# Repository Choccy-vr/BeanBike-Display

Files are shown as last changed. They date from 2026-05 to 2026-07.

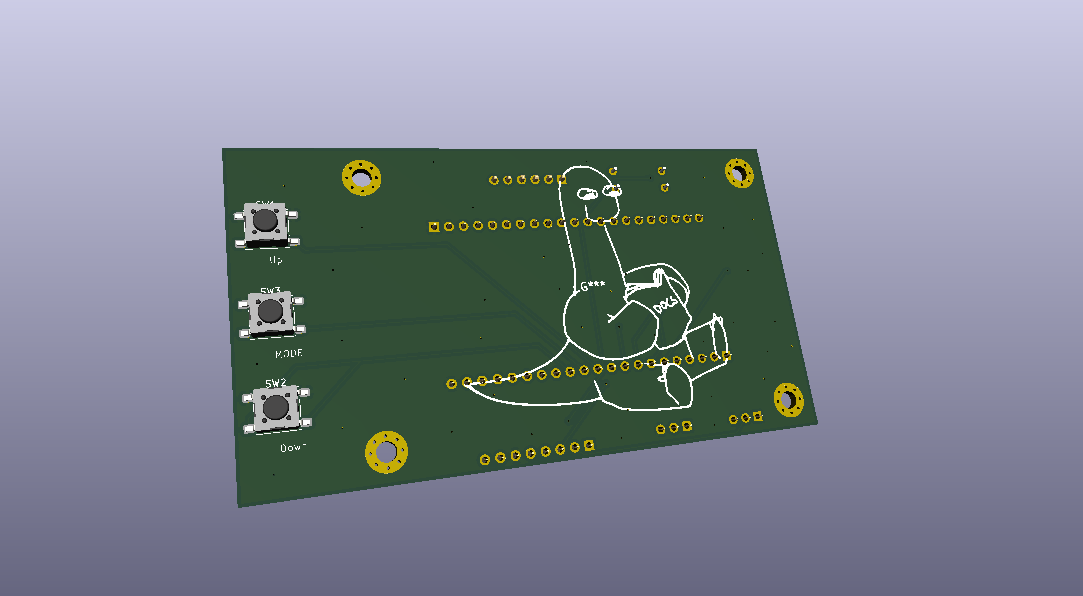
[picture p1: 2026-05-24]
Images/PCB-Bottom.png

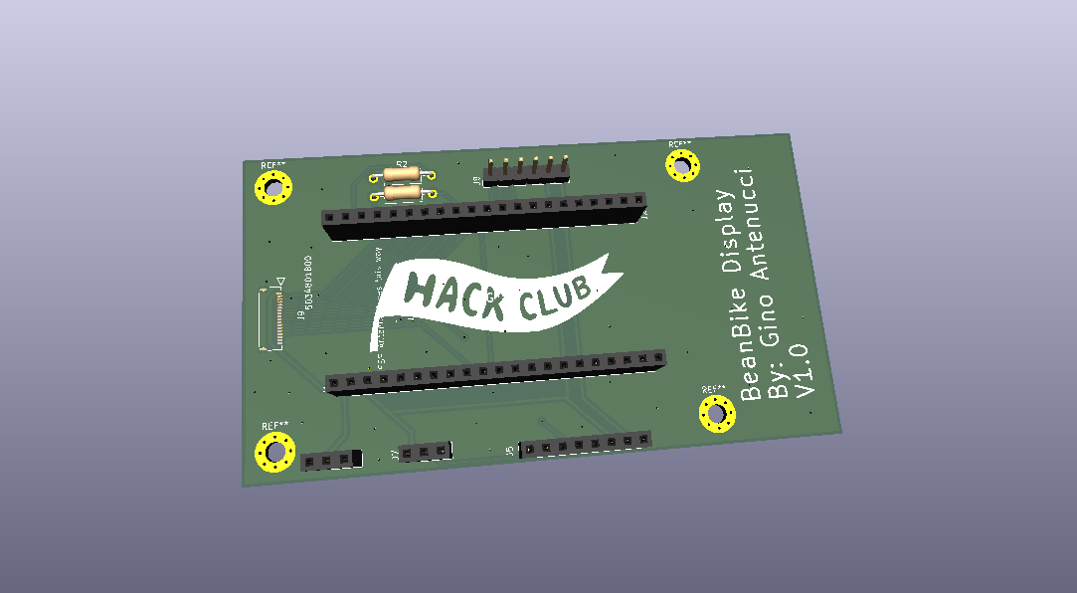
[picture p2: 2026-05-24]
Images/PCB-Top.png

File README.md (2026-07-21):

# BeanBike-Display
### Description
A smart display to use with VESC controllers for Hack Club's Goated YSWS Macondo!!
### Demo
Here is a demo video on YouTube. https://youtu.be/hzEWeqmnlWU
### Specs
- ESP32 S3 N16R8
- Waveshare 480x320 capasitive display
- Custom PCB
### Detailed Description
A smart display using an ESP32 S3 and custom-developed firmware to communicate with VESC devices. Built for eBikes, BeanBike-Display can connect to virtually any VESC controller. With a beautiful 480x320 display from Waveshare to pair with UI designed in Squareline Vision and built with LVGL for fast, beautiful UIs. 
### Why I made this
I made this because I love mobility projects (like e-bikes or anything that moves you around); they are just so fun. This is a successor in a way to a previous project where I tried to create my own BLDC controller (it didn't go well), so this time I am making the display with all the smart functionality and VESC)
### BOM
Note that these are the things that I need funded. Everything else I already have. (The build cost on Macondo is outdated, but I couldn't change it. The cart pics are mostly the same, just with some stuff removed)
|Product Name |Product Description  |Product Link |Product unit price|Product amount|Product Cost|Total (Before Tax + Shipping)|Total (Without Shipping)|Total |
|---|---|---|---|---|---|---|---|---|
|FPC Connector|Connecting to dosplay|https://www.digikey.com/en/products/detail/molex/5034801800/2819155?s=N4IgTCBcDaIKwAYDMAWAHAgjBhIC6AvkA |$1.50 |1 |$1.50 |$8.70 |$9.31 |$19.36|
|PCB |uhh PCB |https://cart.jlcpcb.com/shopcart/cart |$2 |1 |$2 | | | |
|Headers |connecting to ESP |https://www.aliexpress.us/item/3256810564318830.html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|$2.60 |2 |$5.20 | | | |
### Firmware
Open up the firmware folder in PlatformIO and press upload!
## Images

### UI

#### Mockup


#### Built UI


### PCB

#### Schematic


#### Layout


#### 3D PCB
Beanbike-Display
Beanbike-Display-Back

### Built Images





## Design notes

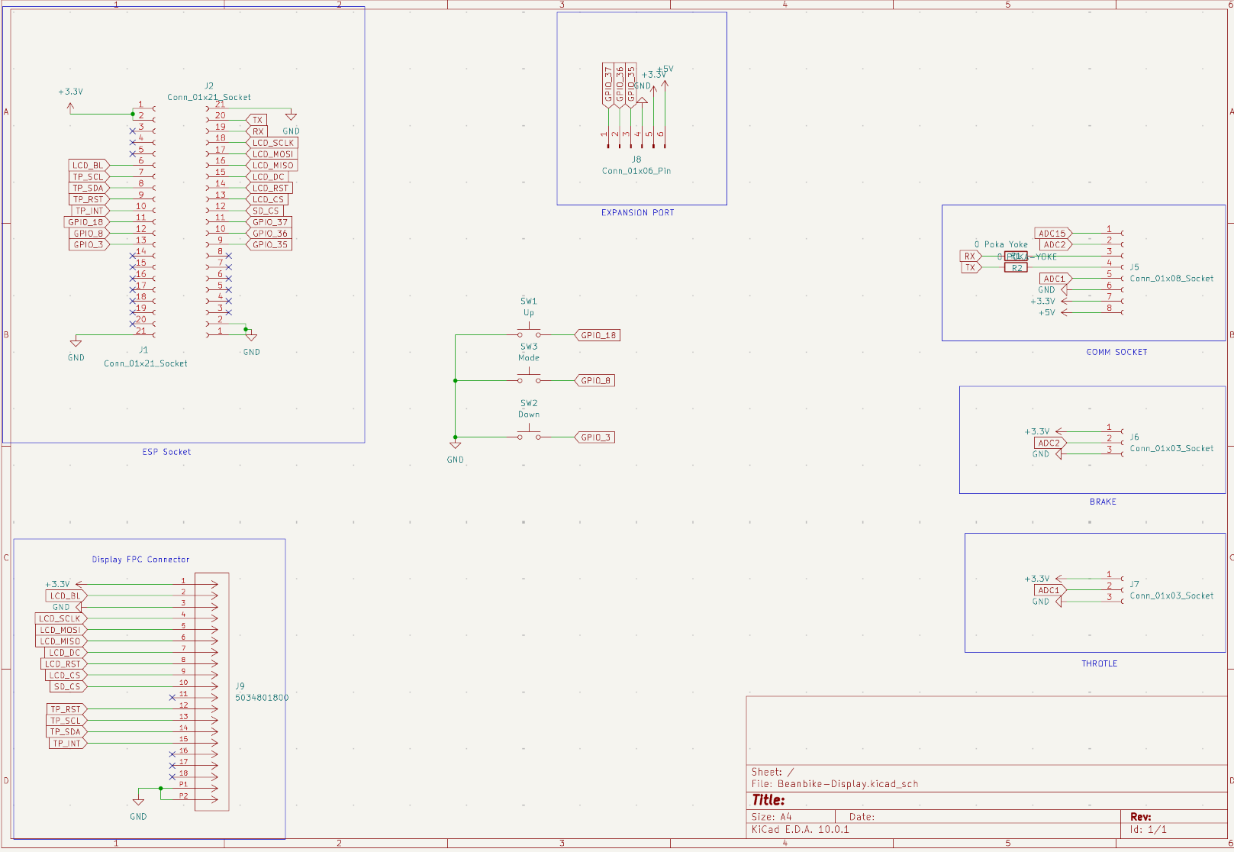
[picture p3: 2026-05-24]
Images/Schematic.png

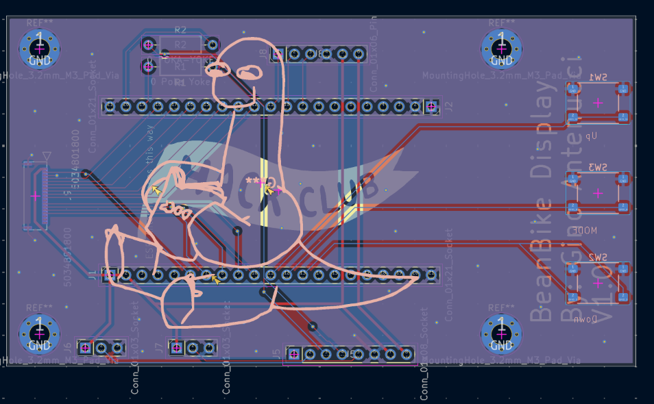
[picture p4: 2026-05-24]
Images/PCB.png

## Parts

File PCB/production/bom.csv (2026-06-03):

Designator | Footprint | Quantity | Value | LCSC Part #
J1, J2 | PinSocket_1x21_P2.54mm_Vertical | 2 | Conn_01x21_Socket
J5 | PinSocket_1x08_P2.54mm_Vertical | 1 | Conn_01x08_Socket
J6, J7 | PinSocket_1x03_P2.54mm_Vertical | 2 | Conn_01x03_Socket
J8 | PinHeader_1x06_P2.54mm_Vertical | 1 | Conn_01x06_Pin
J9 | CON_5034801800_MOL | 1 | 5034801800

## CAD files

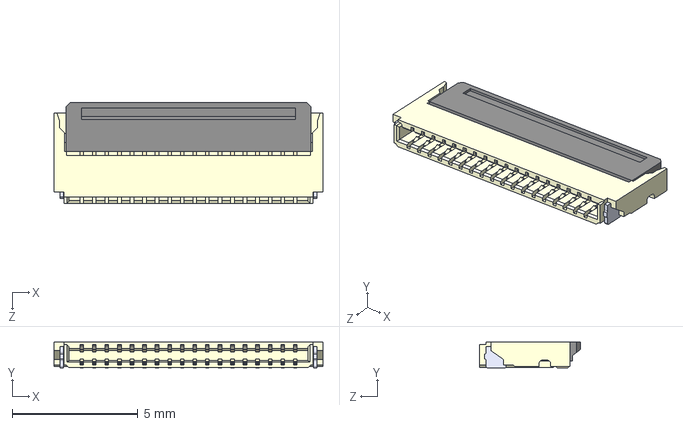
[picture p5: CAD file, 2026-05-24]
PCB/Resources/5034801800 (1)/5034801800.step
10.7 x 1.02 x 4.00 mm

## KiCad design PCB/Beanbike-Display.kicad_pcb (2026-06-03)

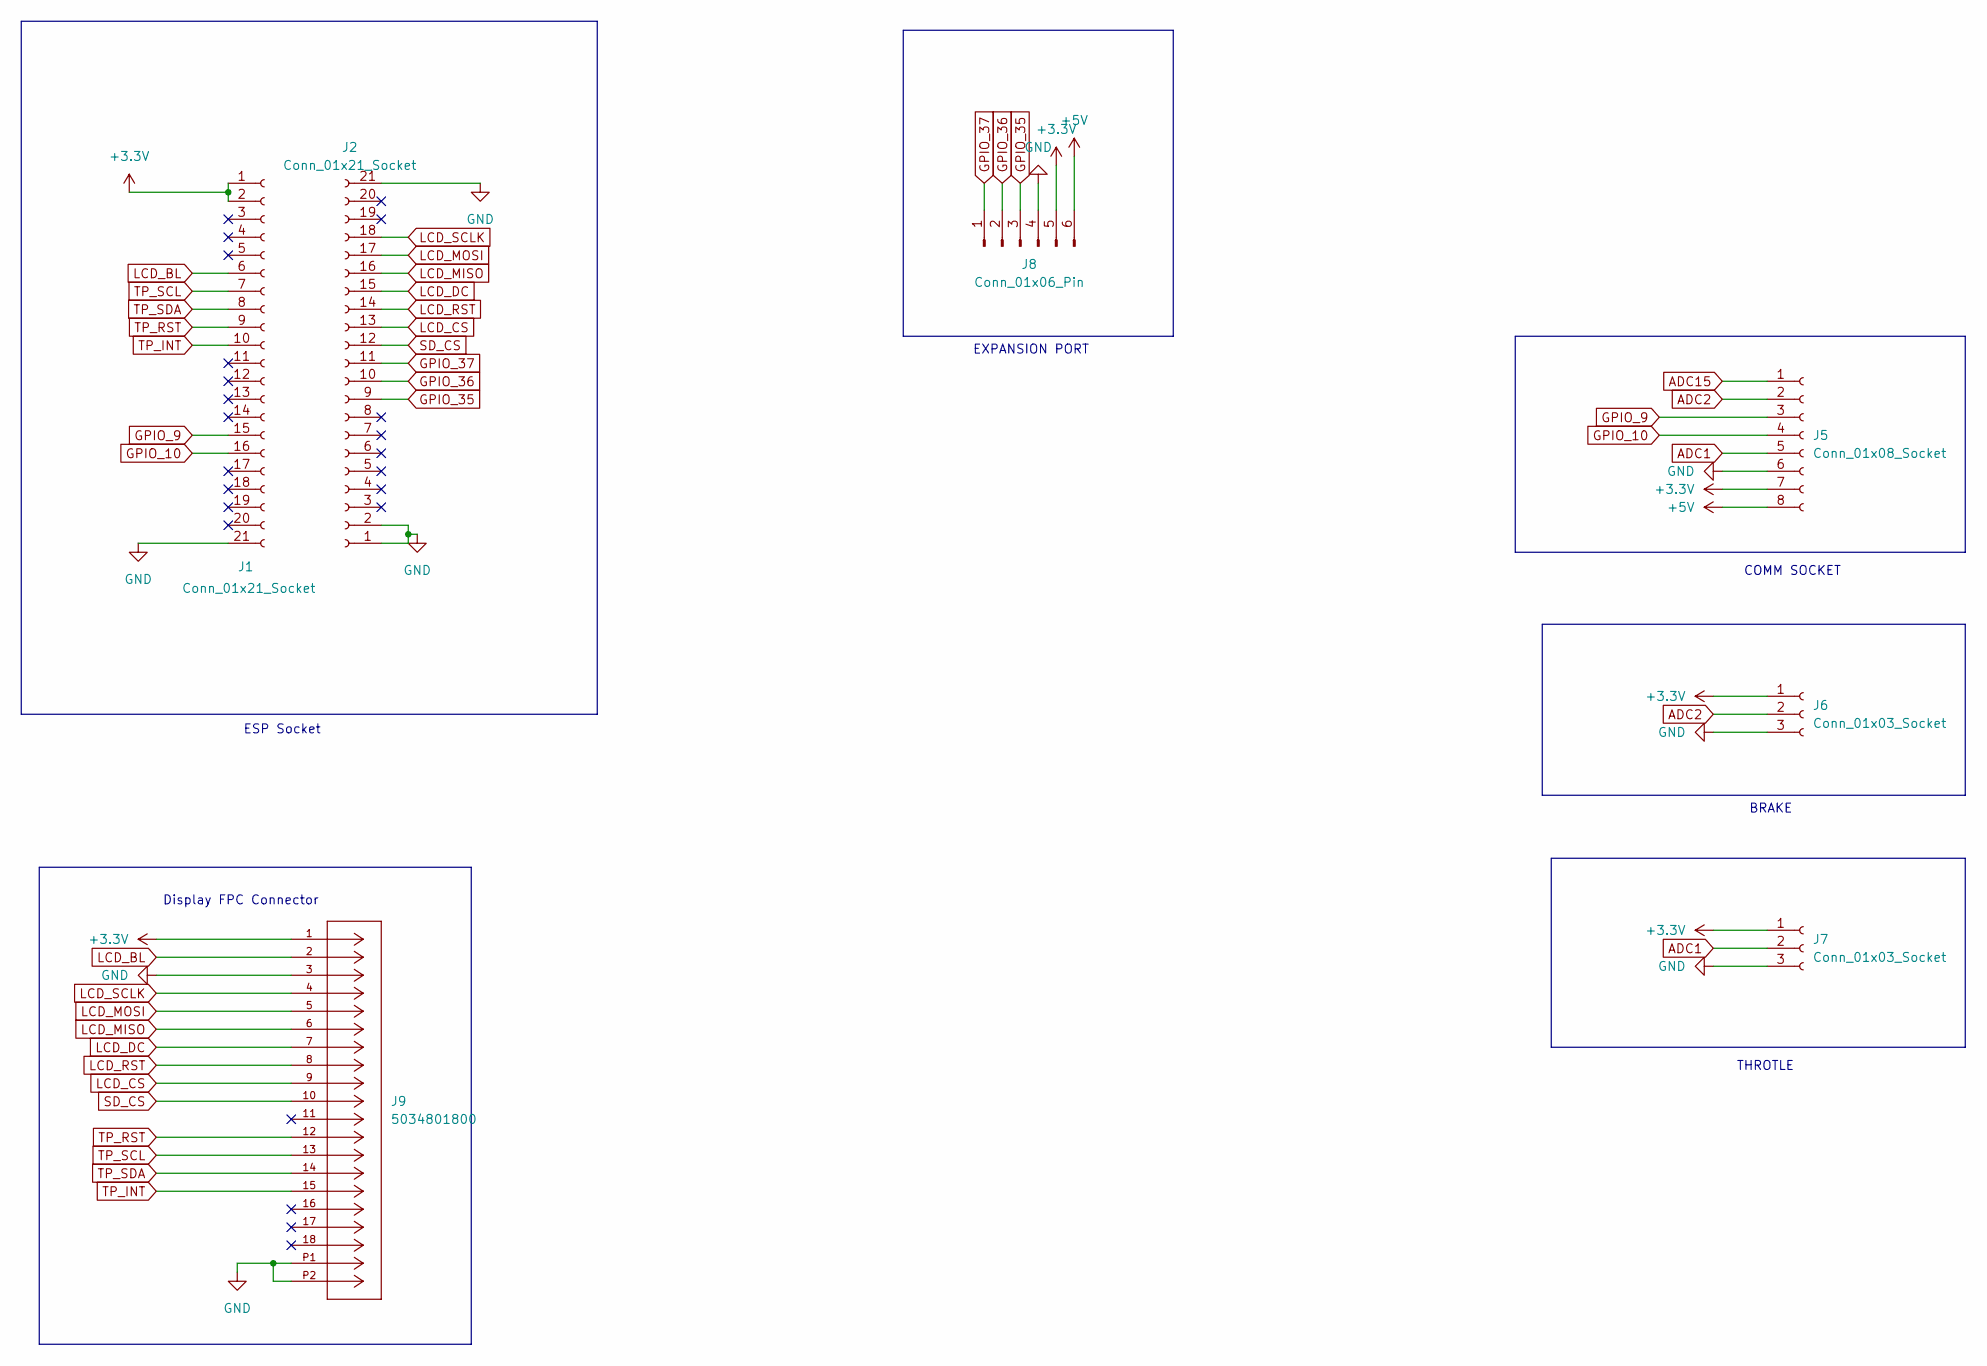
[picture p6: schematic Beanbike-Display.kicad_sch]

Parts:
J1, J2: Conn_01x21_Socket; PinSocket_1x21_P2.54mm_Vertical
J5: Conn_01x08_Socket; PinSocket_1x08_P2.54mm_Vertical
J6, J7: Conn_01x03_Socket; PinSocket_1x03_P2.54mm_Vertical
J8: Conn_01x06_Pin; PinHeader_1x06_P2.54mm_Vertical
J9: 5034801800; CON_5034801800_MOL; MANUFACTURER_PART_NUMBER 5034801800

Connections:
+3.3V: J1.1, J1.2, J5.7, J6.1, J7.1, J8.5, J9.1
+5V: J5.8, J8.6
ADC1: J5.5, J7.2
ADC2: J5.2, J6.2
ADC15: J5.1
GND: J1.21, J2.1, J2.2, J2.21, J5.6, J6.3, J7.3, J8.4, J9.3, J9.P1, J9.P2
GPIO_9: J1.15, J5.3
GPIO_10: J1.16, J5.4
GPIO_35: J2.9, J8.3
GPIO_36: J2.10, J8.2
GPIO_37: J2.11, J8.1
LCD_BL: J1.6, J9.2
LCD_CS: J2.13, J9.9
LCD_DC: J2.15, J9.7
LCD_MISO: J2.16, J9.6
LCD_MOSI: J2.17, J9.5
LCD_RST: J2.14, J9.8
LCD_SCLK: J2.18, J9.4
SD_CS: J2.12, J9.10
TP_INT: J1.10, J9.15
TP_RST: J1.9, J9.12
TP_SCL: J1.7, J9.13
TP_SDA: J1.8, J9.14

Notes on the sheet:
EXPANSION PORT
THROTLE
ESP Socket
BRAKE
Display FPC Connector
COMM SOCKET

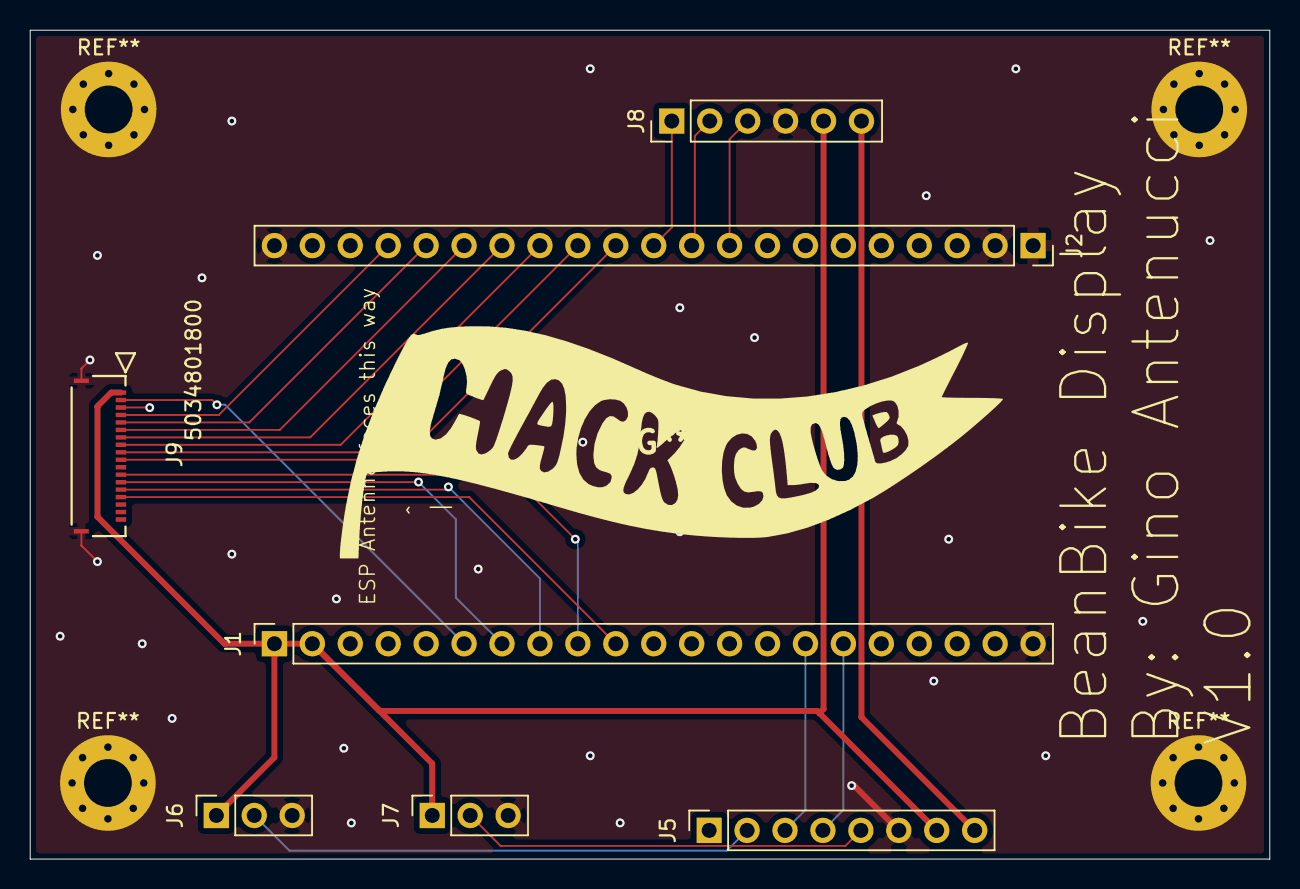
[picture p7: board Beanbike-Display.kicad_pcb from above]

Board: 2 copper layers, 83.0 x 55.5 mm, 7 parts (0 on the bottom side), 22 nets.

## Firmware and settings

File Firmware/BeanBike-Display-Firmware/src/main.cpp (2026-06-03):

#include <Arduino.h>
#include <Wire.h>
#include <lvgl.h>
#include "my_display.hpp"
#include "ui/GUI.h"
#include "backend/vesc/vesc.hpp"

SemaphoreHandle_t ui_mutex = NULL;

#define BUF_SIZE (320 * 50)
static uint8_t lv_buffer[BUF_SIZE] __attribute__((aligned(4)));

static uint32_t my_tick(void)
{
    return millis();
}

void initUI()
{
    GUI_init();

    // Smooth startup animation: Sweep up from 1 to 40
    for (int i = 1; i <= 40; i++)
    {
        lv_arc_set_value(GUI_Arc__MainPage__arc, i * 2);
        char buf[16];
        snprintf(buf, sizeof(buf), "%d", i);
        _ui_label_set_property(GUI_Label__MainPage__20, _UI_LABEL_PROPERTY_TEXT, buf);

        GUI_refresh(); // Update the display
        delay(10);     // 20ms delay controls the speed
    }

    // Sweep down from 40 back to 1
    for (int i = 40; i >= 1; i--)
    {
        lv_arc_set_value(GUI_Arc__MainPage__arc, i * 2);
        char buf[16];
        snprintf(buf, sizeof(buf), "%d", i);
        _ui_label_set_property(GUI_Label__MainPage__20, _UI_LABEL_PROPERTY_TEXT, buf);

        GUI_refresh();
        delay(10);
    }

    lv_arc_set_value(GUI_Arc__MainPage__arc, 0);
    _ui_label_set_property(GUI_Label__MainPage__20, _UI_LABEL_PROPERTY_TEXT, "0");

    _ui_opacity_set(GUI_Label__MainPage__ERROR, 0);
    _ui_label_set_property(GUI_Label__MainPage__label, _UI_LABEL_PROPERTY_TEXT, "0");
}

void setup()
{
    Serial.begin(115200);
    Serial.println("Starting BeanBike Display...");

    // Turn backlight on
    pinMode(6, OUTPUT);
    digitalWrite(6, HIGH);
    // Setup GUI
    lv_init();
    lv_tick_set_cb(my_tick);

    // Initialise screen structure via Lovyan
    lv_lovyan_gfx_create(320, 480, lv_buffer, BUF_SIZE, true);

    ui_mutex = xSemaphoreCreateMutex();

    // Initialize VESC communication after UI is ready
    initVesc();

    initUI();

    xTaskCreatePinnedToCore(VESCTask, "VESCTask", 4096, NULL, 2, NULL, 1); // Run VESC task on core 1
}

void loop()
{
    // UI will step aside if need be
    if (ui_mutex != NULL)
    {
        if (xSemaphoreTake(ui_mutex, 0) == pdTRUE)
        {
            GUI_refresh();
            xSemaphoreGive(ui_mutex);
        }
    }
    delay(30); // ~30 FPS
}

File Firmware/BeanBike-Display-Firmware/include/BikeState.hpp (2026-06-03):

#pragma once

#include <Arduino.h>
#include <VescUart.h>

#define MOTOR_POLE_PAIRS 23.0f      // Change this once you know
#define WHEEL_DIAMETER_INCHES 26.0f // Change this once you know

class BikeObject
{
public:
    float avgMotorCurrent;
    float avgInputCurrent;
    // PWM duty cycle, between 0.0 and 1.0
    float dutyCycleNow;
    float erpm;
    // Battery voltage
    float inputVoltage;
    float ampHours;
    // Regen
    float ampHoursCharged;
    float wattHours;
    // Regen
    float wattHoursCharged;
    long tachometer;
    long tachometerAbs;
    float tempMosfet;
    float tempMotor;
    mc_fault_code error;
    uint8_t majorVersion;
    uint8_t minorVersion;
    // not apart of VESC data
    int odometerMiles;

    float getRpm() { return erpm / MOTOR_POLE_PAIRS; }

    float getMph() { return (getRpm() * WHEEL_DIAMETER_INCHES * PI * 60.0f) / 63360.0f; }

    float getBatteryPercentage()
    {
        // Update with correct battery stats
        float percent = (inputVoltage - 39.0f) / (54.6f - 39.0f) * 100.0f;
        return constrain(percent, 0.0f, 100.0f);
    }

    float getPowerWatts()
    {
        return inputVoltage * avgInputCurrent;
    }

    float getTripDistanceMiles()
    {
        float wheelRevs = (float)tachometerAbs / MOTOR_POLE_PAIRS;

        float inchesTraveled = wheelRevs * (WHEEL_DIAMETER_INCHES * PI);

        return inchesTraveled / 63360.0f;
    }
};

extern BikeObject bike;

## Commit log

2026-05-23 Add Headers
    Init project and add headers needed to connect to the controller
    [Beanbike-Display.kicad_pcb, Beanbike-Display.kicad_sch]
2026-05-24 PCB v1
    [5034801800.step, Beanbike-Display.kicad_pcb, Beanbike-Display.kicad_sch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]
2026-06-03 BikeState & RTOS
    I forgot to commit
    [Beanbike-Display.kicad_pcb, Beanbike-Display.kicad_sch, bom.csv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]
2026-06-26 Add BOM
